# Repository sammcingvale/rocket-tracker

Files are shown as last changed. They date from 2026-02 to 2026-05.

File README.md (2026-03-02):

# 🚀 Rocket Tracker

A computer vision system that visually tracks model rockets in flight and points a laser at them. Built as a learning project covering OpenCV, Kalman filters, PID control, servo/brushless motor control, and real-time embedded systems.

## Project Phases

| Phase | Status | Description |
|---|---|---|
| 1. Software Tracking | ✅ Complete | Color detection + Kalman filter in OpenCV |
| 2. Pan/Tilt Gimbal | ✅ Complete | MG995 servos, Arduino UNO R4 WiFi, serial control |
| 3. Closed-Loop Control | ✅ Complete | Camera-on-gimbal PID tracking, person detection, live tuning |
| 4. Hardware Upgrade | 🔧 In Progress | Brushless gimbal motors (2804 + SimpleFOC), laser pointer |
| 5. Outdoor Rocket Tracking | 📋 Planned | Field testing with model rockets |

## System Architecture

```
Camera → OpenCV Detection → Kalman Filter → PID Controller → Serial → Arduino → Servos
  ↑                                                                              |
  └──────────────────── closed-loop feedback ──────────────────────────────────────┘
```

## Hardware Wiring

Hardware Wiring Diagram

### Current Hardware (Phase 2-3)
- Arduino UNO R4 WiFi
- 2x MG995 metal gear servos
- Bolsen aluminum pan/tilt bracket
- Logitech C920 webcam
- 6V 2A power supply

### Planned Hardware (Phase 4)
- MKS Dual FOC V3.2 + ESP32 controller
- 2x 2804 brushless gimbal motors with AS5600 encoders
- 5mW 650nm red laser module
- 12V 3A power supply

## Repository Structure

```
rocket-tracker/
├── vision/                     # Detection & tracking code
│   ├── track_color.py          # Phase 1a: HSV color detection with calibration
│   └── track_kalman.py         # Phase 1b: Kalman filter tracking
├── control/                    # Gimbal control code
│   ├── track_gimbal.py         # Phase 3: Closed-loop PID tracking (main script)
│   └── servo_serial.py         # Phase 2: Serial interface to Arduino
├── firmware/                   # Arduino code
│   └── servo_controller/
│       └── servo_controller.ino  # Servo control firmware (UNO R4 WiFi)
├── hardware/                   # Wiring diagrams, CAD files
│   └── wiring_diagram.svg
├── docs/                       # Documentation & learning resources
│   ├── notebook.md             # Engineering notebook / build log
│   ├── assembly_guide.md       # Step-by-step gimbal assembly instructions
│   ├── phase4_hardware.md      # Phase 4 shopping list & rationale
│   ├── camera_sensor_diagram.html  # Interactive: how camera sensors work
│   └── kalman_deep_dive.html   # Interactive: Kalman filter visualization
├── experiments/                # Test scripts
├── requirements.txt
└── README.md
```

## Quick Start

### Setup
```bash
git clone https://github.com/YOUR_USERNAME/rocket-tracker.git
cd rocket-tracker
python -m venv venv
source venv/bin/activate
pip install -r requirements.txt
```

### Phase 1: Software-Only Tracking (no hardware needed)
```bash
# Basic color detection — press 'c' to calibrate HSV
python vision/track_color.py

# With Kalman filter prediction
python vision/track_kalman.py
```

### Phase 2: Servo Testing
1. Upload `firmware/servo_controller/servo_controller.ino` via Arduino IDE
2. Board: Arduino UNO R4 WiFi, Baud: 115200
```bash
# Interactive servo commands
python control/servo_serial.py

# Automated demo sequence
python control/servo_serial.py --demo
```

### Phase 3: Closed-Loop Tracking
```bash
# Full tracking with gimbal (auto-detects Arduino)
python control/track_gimbal.py --camera 1

# Vision-only mode (no Arduino needed)
python control/track_gimbal.py --camera 0 --no-serial
```

#### Tracking Controls (press in camera window)
| Key | Action |
|-----|---|
| `q` | Quit |
| `h` | Home servos to center |
| `p` | Pause/resume tracking |
| `c` | Toggle HSV calibration |
| `s` | Print current HSV values |
| `1` / `2` / `3` | PID preset: conservative / balanced / aggressive |
| `+` / `-` | Fine-tune P gain |
| `x` / `y` | Flip pan / tilt direction |
| `m` | Toggle detection mode (color / person) |

#### HSV Calibration
Default values tuned for a red marker cap against mixed backgrounds:
- Lower: `[0, 180, 50]`
- Upper: `[10, 255, 255]`

Press `c` to open calibration sliders and adjust for your object/environment.

## Key Concepts Learned

### Computer Vision
- **HSV color space** — separating color (hue) from brightness for robust detection
- **Morphological operations** — erode/dilate to clean up binary masks
- **Contour detection** — finding object boundaries in filtered images

### State Estimation
- **Kalman filter** — predicting object position during detection dropouts using a constant-velocity model
- **Measurement vs. prediction** — using raw measurements for PID, Kalman only for coasting

### Control Theory
- **PID control** — proportional correction of pixel error to servo angle adjustment
- **Closed-loop feedback** — camera mounted on gimbal creates a true feedback loop
- **Tuning** — P-only control with dead zone works best for this system; I causes integral windup, D amplifies detection noise
- **Output clamping** — limiting max degrees/frame prevents saturation and oscillation

### Embedded Systems
- **Serial communication** — laptop ↔ Arduino over USB at 115200 baud
- **PWM servo control** — pulse width encoding for hobby servos
- **Common ground** — shared voltage reference between separate power supplies
- **Arduino UNO R4 WiFi** — USB CDC serial requires timeout on `while(!Serial)`

## Current PID Settings (Phase 3)

```
Conservative:  P=0.015  I=0  D=0  (output limit: 1.5°/frame)
Balanced:      P=0.03   I=0  D=0
Aggressive:    P=0.06   I=0  D=0
Dead zone:     ±15 pixels (ignores sub-pixel detection noise)
```

## License

This is a personal learning project. Feel free to use it for your own learning.

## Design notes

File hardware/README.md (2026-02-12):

# Hardware

CAD files, wiring diagrams, and BOM (bill of materials).

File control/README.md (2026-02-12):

# Control Module

PID loops, gimbal interface, and coordinate transforms.

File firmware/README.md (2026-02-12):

# Firmware

Arduino/embedded code for servo and motor control.

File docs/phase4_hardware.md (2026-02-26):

# Phase 4 Hardware Shopping List

## Why SimpleFOC Instead of BGC?

BGC (SimpleBGC/AlexMos) controllers are designed for camera *stabilization* — they use IMU data to keep a camera level despite external movement. That's the opposite of what we want. We need *active tracking*: "point at this angle, now this angle, now this angle" at high speed.

SimpleFOC is an open-source Arduino FOC (Field Oriented Control) library. It gives us direct position/velocity control of brushless motors using the same Arduino IDE workflow we already have. Same serial command interface, same development flow — just dramatically faster, smoother motors.

---

## The Shopping List

### 1. Motor Controller — MKS Dual FOC V3.2 + ESP32 (~$30-40)

**What:** A single board that drives TWO brushless motors, with an ESP32 microcontroller built in.

**Search:** "MKS Dual FOC V3.2 ESP32" on Amazon

**Why this one:**
- Drives both pan AND tilt motors from one board (no need for two drivers)
- ESP32 has WiFi + Bluetooth (wireless control later!)
- Built-in current sensors for FOC
- Directly compatible with the SimpleFOC Arduino library
- Programs through Arduino IDE just like your UNO R4
- 12V input, which matches the motors below

**Note:** Make sure you get the version WITH the ESP32 module (sometimes sold separately). The listing should say "Dual FOC Plus-ESP32" or similar.

---

### 2. Gimbal Motors (x2) — 2804 with AS5600 Encoder (~$15-20 each)

**What:** Brushless DC motors specifically designed for gimbals, with a magnetic position encoder built in.

**Search:** "2804 brushless gimbal motor AS5600 encoder" on Amazon
  - or "Makerbase gimbal motor 2804 AS5600"
  - DFRobot also sells a nice one (search "DFRobot 2804 BLDC")

**Why these:**
- The AS5600 encoder gives 12-bit resolution = 0.087° accuracy (vs ~1° with servos)
- SimpleFOC library has native AS5600 support over I2C
- Low KV rating = high torque at low speeds (perfect for gimbal, NOT for propellers)
- Compact: ~34mm diameter
- Hollow shaft design allows cable routing through the motor

**You need 2:** one for pan, one for tilt.

**Why brushless motors are faster than servos:**
Your MG995 servos have internal gears and top out at ~400°/sec with significant backlash. Brushless gimbal motors are direct-drive (no gears), so there's zero backlash and they can reposition in milliseconds. The motor *is* the joint.

---

### 3. Power Supply — 12V 3A DC Adapter (~$10-12)

**What:** Wall adapter to power the motors and controller.

**Search:** "12V 3A DC power supply barrel jack" on Amazon

**Why:** The 2804 motors are rated for 12V. Your existing 6V adapter won't work. 3A gives enough headroom for both motors under load.

**Alternative:** A 3S LiPo battery (11.1V) works too if you want it portable for outdoor testing later. But a wall adapter is simpler for now.

---

### 4. Laser Module — 5mW 650nm Red Dot (~$8-12)

**What:** A small focusable laser diode that mounts on the gimbal platform alongside the camera.

**Search:** "focusable 650nm 5mW red dot laser module 5V" on Amazon
  - The Adafruit one (product #1054) is reliable: "Adafruit laser diode 5mW 650nm"
  - Amazon generic: "adjustable focus 5mW 650nm laser diode module 3-5V"

**Specs to look for:**
- 650nm wavelength (red, highly visible)
- 5mW power (Class IIIa — visible but eye-safe at reasonable distances)
- 3-5V operating voltage (can be powered from the ESP32's 3.3V or 5V pin)
- Focusable lens (adjustable dot size for different distances)
- Wire leads (red +, black -)

**DO NOT buy anything over 5mW** — higher power lasers are dangerous and unnecessary. 5mW is bright enough to see the dot on a rocket at distance.

**Safety:** Never look directly into the beam or point it at people/aircraft. We'll add a software safety interlock (laser only activates when tracking is active).

---

### 5. Breadboard + Jumper Wires (~$8)

**What:** You still need a breadboard from Phase 2, and it'll be useful here too for prototyping connections.

**Search:** "mini breadboard jumper wire kit" on Amazon

---

### 6. Gimbal Frame — 3D Printed or Fabricated

**This is the one item you can't just buy off the shelf,** because the Bolsen bracket was designed for standard servos, not brushless motors.

**Options (pick one):**
- **3D print:** If you have access to a 3D printer (library, makerspace, friend), I can generate an STL file designed for the 2804 motors
- **Thingiverse:** Search "SimpleFOC 2804 pan tilt" — there are several community designs
- **Fabricate from aluminum L-brackets:** Buy some aluminum angle from a hardware store and drill mounting holes. Less pretty, but functional
- **Adapt the Bolsen bracket:** With creative mounting (epoxy, zip ties, 3D printed adapter plates), you might be able to attach 2804 motors to the existing bracket

We can figure this out once the electronic parts arrive. The software work can happen immediately.

---

## Summary

| Item | Est. Price | Notes |
|---|---|---|
| MKS Dual FOC V3.2 + ESP32 | ~$30-40 | One board drives both motors |
| 2804 Gimbal Motor + AS5600 (x2) | ~$30-40 | Position accuracy: 0.087° |
| 12V 3A Power Supply | ~$10-12 | Wall adapter for bench testing |
| 5mW 650nm Laser Module | ~$8-12 | Focusable, 3-5V, wire leads |
| Mini Breadboard + Wires | ~$8 | If you don't have one yet |
| Gimbal Frame | $0-30 | 3D print or fabricate |
| **TOTAL** | **~$86-140** | |

---

## What Changes in the Software

The great news: not much! The control flow stays the same:

```
Camera → OpenCV → Kalman → PID → Serial → Motor Controller → Motors
```

What changes:
- Arduino firmware switches from Servo library → SimpleFOC library
- Serial commands send precise float angles instead of integer degrees
- ESP32 replaces Arduino UNO R4 (but same Arduino IDE, same workflow)
- PID gains will need re-tuning (faster motors = less aggressive P needed)
- Add laser on/off control (digital pin HIGH/LOW)

Your UNO R4 + servos become your backup/test rig, which is handy.

---

## What To Do While Hardware Ships

1. **Mount the C920 on the current servo gimbal** and test closed-loop tracking
2. **Tune PID** on the servo system — this knowledge transfers directly
3. **I'll write the SimpleFOC firmware** so it's ready when parts arrive
4. **Build/find a gimbal frame design** for the 2804 motors

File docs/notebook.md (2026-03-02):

# Engineering Notebook

## Project: Rocket Tracker
**Goal:** Build a system that visually tracks model rockets in flight and points a laser at them.

---

## Phase 1: Software Tracking

### 1a: Color Detection (`vision/track_color.py`)
- HSV-based color detection for a red marker cap
- Gaussian blur → HSV conversion → binary mask → morphological ops → contour detection
- Interactive calibration mode with trackbars
- Key learning: HSV separates color from brightness, making detection robust to lighting changes
- Challenge: white backgrounds wash out saturation via auto-exposure; fast motion causes blur

### 1b: Kalman Filter (`vision/track_kalman.py`)
- Added constant-velocity Kalman filter (state: [x, y, vx, vy])
- Predict step extrapolates position using velocity model
- Update step blends prediction with measurement
- Coasts on velocity estimate when detection is lost
- Parameters: R=25 (measurement noise), Q_pos=4, Q_vel=16 (process noise)

### Interactive Learning Resources
- `docs/camera_sensor_diagram.html` — how camera sensors work (Bayer filter, demosaicing)
- `docs/kalman_deep_dive.html` — step-by-step Kalman filter visualization

---

## Phase 2: Pan/Tilt Gimbal

### Hardware
- Arduino UNO R4 WiFi
- 2x MG995 metal gear servos (pan on D9, tilt on D10)
- Bolsen aluminum 2-DOF pan/tilt bracket
- 6V 2A external power supply (servos powered separately from Arduino)
- Common ground between Arduino GND and servo power supply GND

### Firmware (`firmware/servo_controller/servo_controller.ino`)
- Serial command protocol: P<angle>, T<angle>, B<pan,tilt>, H (home), S (sweep), C (query)
- Smooth interpolation (STEP_SIZE=2, STEP_DELAY=5ms) to reduce jerk
- Baud rate: 115200
- Key fix: `while(!Serial)` must have a 3-second timeout on R4 WiFi, otherwise it blocks when connecting from pyserial (vs Arduino IDE Serial Monitor)

### Serial Interface (`control/servo_serial.py`)
- Auto-detects Arduino serial port across Mac/Linux/Windows
- Interactive mode + automated demo sequence
- 2-second delay after connection for Arduino bootloader reset

### Lessons Learned
- UNO R4 WiFi uses USB CDC (software serial), not hardware UART — `while(!Serial)` behaves differently than classic UNO
- Always power servos externally, never from Arduino 5V pin
- Common ground is mandatory for PWM signal integrity

---

## Phase 3: Closed-Loop Tracking

### System (`control/track_gimbal.py`)
- Camera mounted on gimbal creates true closed-loop feedback
- Detection → raw pixel error → PID → servo angle adjustment → serial → Arduino
- Kalman filter used only for coasting (when detection lost), NOT for PID input
- Key insight: Kalman velocity estimate is unreliable in closed-loop because apparent frame motion mixes object velocity with gimbal movement

### PID Tuning Journey
1. Started with P=0.06, I=0.002, D=0.02 — violent oscillation
2. Discovered output was saturating at ±5°/frame every frame (not proportional at all)
3. Reduced output limit to 1.5°/frame — proportional behavior restored
4. Zeroed I term — was causing integral windup and circling
5. Zeroed D term — was amplifying frame-to-frame detection noise (÷ by dt=0.033 → huge derivatives)
6. Added ±15px dead zone — stops chasing detection noise when nearly centered
7. Final: P-only control with output clamping and dead zone

### Final PID Settings
```
Conservative:  P=0.015  I=0  D=0  (best for stable tracking)
Balanced:      P=0.03   I=0  D=0  (slight circling on noisy backgrounds)
Aggressive:    P=0.06   I=0  D=0  (for fast targets)
Output limit:  1.5°/frame (45°/sec max at 30fps)
Dead zone:     ±15 pixels
```

### Direction Inversion
- Pan and tilt correction direction depends on physical servo mounting
- Runtime toggle: 'x' flips pan, 'y' flips tilt
- Current config: PAN_INVERT=1, TILT_INVERT=-1
- Also removed cv2.flip() mirror since camera is outward-facing on gimbal

### Serial Reliability
- Added write_timeout=0.1 to prevent blocking when Arduino buffer fills
- Added reset_input_buffer() before each write to drain responses
- Connection test: sends '?' and checks for response on startup

### HSV Calibration
- Original (Phase 1): lower=[160, 180, 0], upper=[179, 255, 255]
- Updated (Phase 3): lower=[0, 180, 50], upper=[10, 255, 255]
- Different shade of red (hue 0-10 vs 160-179), high saturation floor rejects white backgrounds

### Detection Smoothing
- Added rolling average of last N centroids (SMOOTH_WINDOW=3) between detection and PID
- Raw detection still feeds Kalman filter (it has its own smoothing)
- Smoothed detection feeds PID — reduces frame-to-frame jitter noticeably
- Buffer clears on detection loss to prevent stale data leaking in

### Home Position Calibration
- Python-side home() was sending firmware's hardcoded 'H' command (always 90/90)
- Fixed: home() now calls send_angles(SERVO_PAN_HOME, SERVO_TILT_HOME)
- Allows per-axis calibration in Python config (e.g., SERVO_TILT_HOME=80 to aim camera up)

### Person Tracking Mode
- Press 'm' to toggle between color detection and person detection
- Three cascading detectors in priority order:
  1. Upper body Haar cascade — works with torso + head visible (best for low camera)
  2. Face Haar cascade — works with head/shoulders only
  3. HOG full body — fallback when full body in frame
- Aiming point: center of detected region (chest for upper body, center for face)
- Lesson: HOG detector needs head-to-knees visible — useless from a low table
- Lesson: Haar cascades produce false positives on symmetric objects (grandfather clock, picture frames)

### Persistence Filter
- Problem: Haar cascades fire on furniture, clock pendulums, etc.
- Solution: new detections must appear within 80px of the same spot for 3 consecutive frames
- Once confirmed, single-frame detections accepted (no lag during active tracking)
- Resets after 10 frames without detection, requiring re-confirmation
- Tightened cascade thresholds: minNeighbors 3→5, larger minSize

### PID Tuning Dashboard
- Interactive React simulation of the gimbal system (`docs/pid_dashboard.jsx`)
- Same PID math, dead zone, output clamp, pixel-to-degree conversion as real system
- Drag target in camera view, adjust P/I/D sliders, watch real-time graphs
- Presets match real tracker (conservative, balanced, aggressive, try-I, try-D)
- Key experiments: I-term windup visible, saturation visible, dead zone behavior

### System Architecture Deep Dive
- Interactive 9-stage pipeline diagram (`docs/system_diagram.jsx`)
- Latency analysis: ~55ms total, servo response (20ms) is biggest bottleneck
- Two independent PID controllers (pan + tilt) with shared gains
- Three feedback loops identified: visual (intentional), mechanical coupling (parasitic), Kalman coasting (open-loop fallback)

### Current State
- Stable face tracking of walking person with conservative PID
- Detection is now the weakest link, not control — exactly where we want to be
- HSV color tracking hit its ceiling (lighting sensitivity, false matches)
- Haar cascades work but are brittle — neural detector (MobileNet SSD, MediaPipe) is the natural next step
- All PID/smoothing/persistence work carries forward regardless of detection method

---

## Phase 4: Brushless Motor Upgrade (hardware arrived!)

### Components
- MKS Dual FOC V3.2 + ESP32 (dual brushless motor driver)
- 2x 2804 brushless gimbal motor + AS5600 encoder
- 12V 3A power supply
- 5mW 650nm red laser module

### Why Brushless
- MG995 servos: ~400°/sec, ~1° accuracy, gear backlash, holding vibration
- 2804 brushless + AS5600: direct drive, 0.087° accuracy, no backlash, 1-3ms response
- Expected latency improvement: motor stage from ~20ms to ~2ms
- SimpleFOC library provides Arduino-compatible FOC control

### Key Challenge
- Two AS5600 encoders share same I2C address (0x36)
- Solution: one on I2C, one on analog/PWM output

### Frame
- Need custom 3D-printed frame for 2804 motors (Bolsen bracket is servo-specific)
- Access to makerspace for printing

---

## Phase 5: Outdoor Rocket Tracking (planned)

### Camera Considerations
- C920 may be sufficient at distance (rocket = few pixels, slow apparent motion)
- OV9281 global shutter module (720p@120fps) available as upgrade if needed (~$30-50)
- Decision: test with C920 first, upgrade based on real data

### Additional Challenges
- Sky backgrounds (blue/white) — will need different detection strategy
- Rocket is small at distance — few pixels to detect
- Motor burn exhaust — thermal signature as alternative detection
- Gravity — add gravity term to Kalman filter for ballistic prediction

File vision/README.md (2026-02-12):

# Vision Module

Detection and tracking code.

## Phase 1 Scripts
- `track_color.py` — basic color-based object tracking (first exercise)

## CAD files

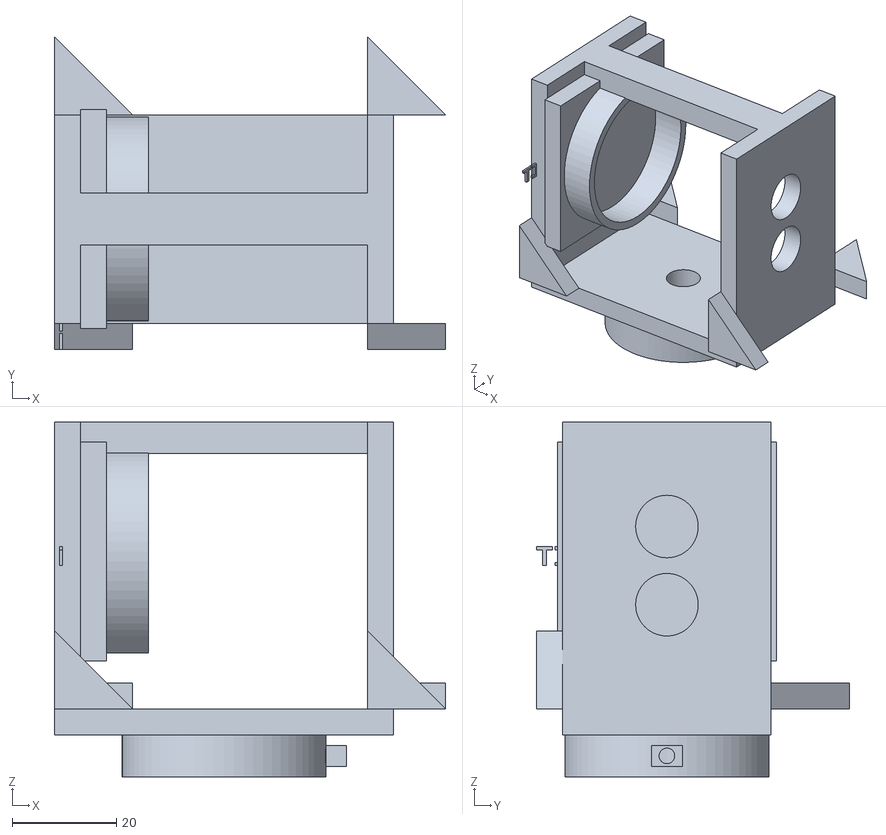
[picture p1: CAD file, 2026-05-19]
hardware/stl/gimbal_yoke.stl
75.0 x 60.0 x 68.0

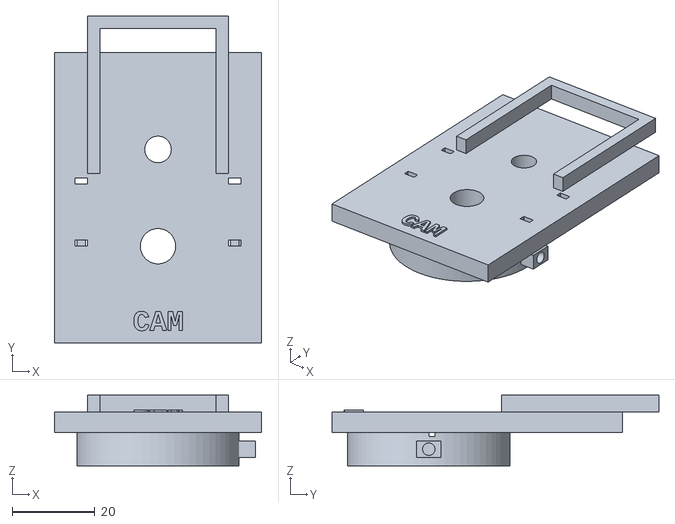
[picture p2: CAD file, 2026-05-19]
hardware/stl/gimbal_camera_mount.stl
50.0 x 78.8 x 17.0

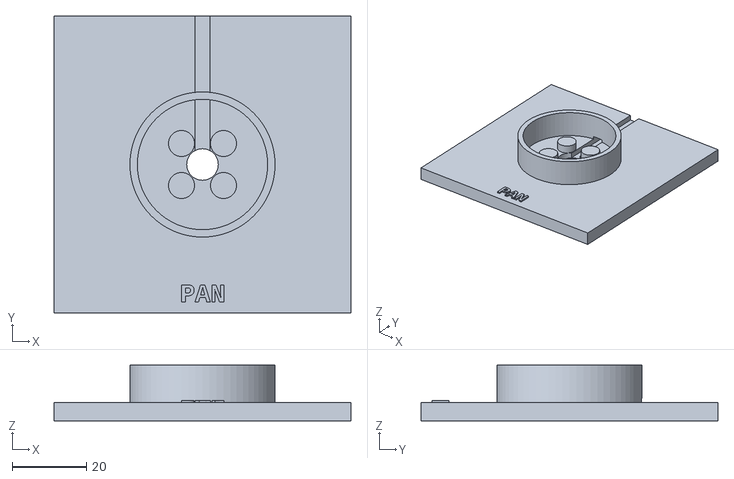
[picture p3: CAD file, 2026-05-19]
hardware/stl/gimbal_base.stl
80.0 x 80.0 x 15.0

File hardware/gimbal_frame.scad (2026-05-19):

/*
 * 2-Axis Pan/Tilt Gimbal Frame
 * For 2804 Hollow Shaft Outrunner Brushless Motors + AS5600 Encoders
 * 
 * HOW TO USE:
 *   1. Open this file in OpenSCAD (free: https://openscad.org/downloads)
 *   2. Uncomment ONE of the three lines at the bottom:
 *        base();
 *        yoke();
 *        camera_mount();
 *   3. Press F6 (Render)
 *   4. File → Export as STL
 *   5. Import STL into Bambu Studio
 *   6. Repeat for each part
 *
 * PRINT SETTINGS (Bambu P1S):
 *   Material: PLA or PETG
 *   Layer height: 0.2mm
 *   Infill: 30-40% (gyroid or grid)
 *   Walls: 3 perimeters
 *   Supports: YES for yoke (the arms overhang)
 *   Print yoke upright (arms pointing up)
 *   Print base flat (feet down)
 *   Print camera mount flat
 */

// ============================================================
// MOTOR DIMENSIONS — edit these if your measurements differ
// ============================================================
motor_dia       = 34.5;   // Motor body outer diameter
motor_height    = 15.0;   // Motor body height
bolt_circle     = 16.0;   // Mounting hole center-to-center (diagonal)
num_bolts       = 4;      // Number of mounting holes
screw_dia       = 2.2;    // M2 hole + clearance
screw_depth     = 3.0;    // Max screw depth into motor
hollow_shaft    = 6.5;    // Center hollow opening
magnet_dia      = 8.0;    // AS5600 magnet diameter (if applicable)

// ============================================================
// DESIGN PARAMETERS — tweak fit and strength
// ============================================================
tol             = 0.3;    // Print tolerance (increase if too tight)
wall            = 4.0;    // General wall thickness
$fn             = 64;     // Cylinder smoothness (increase for smoother)

// Derived
motor_r         = motor_dia / 2;
bolt_r          = bolt_circle / 2;
screw_r         = screw_dia / 2;

// ============================================================
// HELPER: Motor bolt hole pattern
// ============================================================
module bolt_holes(depth=10, extra_r=0) {
    for (i = [0:num_bolts-1]) {
        angle = 360 / num_bolts * i + 45; // 45° offset
        translate([bolt_r * cos(angle), bolt_r * sin(angle), 0])
            cylinder(h=depth, r=screw_r + extra_r, center=true);
    }
}

// ============================================================
// HELPER: Motor clamp ring
// ============================================================
module clamp_ring(height=10, inner_tol=0) {
    difference() {
        cylinder(h=height, r=motor_r + wall/2 + tol, center=false);
        translate([0, 0, -1])
            cylinder(h=height+2, r=motor_r + tol + inner_tol, center=false);
    }
}

// ============================================================
// PART 1: BASE
// ============================================================
module base() {
    base_w = 80;
    base_d = 80;
    base_h = 5;
    ring_h = 10;     // Motor retention ring height above base
    standoff_h = 3;  // Motor mount standoff height above base
    
    difference() {
        union() {
            // Main plate
            translate([-base_w/2, -base_d/2, 0])
                cube([base_w, base_d, base_h]);
            
            // Motor retention ring
            translate([0, 0, base_h])
                clamp_ring(height=ring_h);
            
            // Motor mounting standoffs
            for (i = [0:num_bolts-1]) {
                angle = 360 / num_bolts * i + 45;
                translate([bolt_r * cos(angle), bolt_r * sin(angle), base_h])
                    cylinder(h=standoff_h, r=3.5);
            }
        }
        
        // Subtract: motor mounting screw holes (through standoffs and base)
        translate([0, 0, -1])
            bolt_holes(depth=base_h + standoff_h + 4);
        
        // Subtract: center wiring hole
        translate([0, 0, -1])
            cylinder(h=base_h + ring_h + 4, r=hollow_shaft/2 + 1);
        
        // Subtract: cable channel to edge
        translate([-2, 0, base_h - 2])
            cube([4, base_d, 3]);
    }
    
    // Label
    translate([0, -base_d/2 + 3, base_h])
        linear_extrude(0.5)
            text("PAN", size=5, halign="center", font="Liberation Mono:style=Bold");
}

// ============================================================
// PART 2: YOKE (connects pan rotor → tilt motor)
// ============================================================
module yoke() {
    arm_h = 55;         // Arm height
    arm_t = wall + 1;   // Arm thickness (5mm)
    arm_d = 40;         // Arm depth (front-to-back)
    yoke_w = 65;        // Total width
    plate_h = 5;        // Bottom plate thickness
    clamp_depth = 8;    // Motor clamp ring depth (below plate)
    
    motor_z = plate_h + arm_h * 0.55;  // Tilt motor center height
    
    difference() {
        union() {
            // Bottom plate
            translate([-yoke_w/2, -arm_d/2, 0])
                cube([yoke_w, arm_d, plate_h]);
            
            // Motor clamp ring (goes below plate, fits over pan rotor)
            translate([0, 0, -clamp_depth])
                clamp_ring(height=clamp_depth + 1);
            
            // Left arm
            translate([-yoke_w/2, -arm_d/2, plate_h])
                cube([arm_t, arm_d, arm_h]);
            
            // Right arm
            translate([yoke_w/2 - arm_t, -arm_d/2, plate_h])
                cube([arm_t, arm_d, arm_h]);
            
            // Tilt motor mount plate (on inner face of left arm)
            mount_size = 42;
            mount_t = 5;
            translate([-yoke_w/2 + arm_t, -mount_size/2, motor_z - mount_size/2])
                cube([mount_t, mount_size, mount_size]);
            
            // Tilt motor retention ring (horizontal, on left mount plate)
            translate([-yoke_w/2 + arm_t + mount_t, 0, motor_z])
                rotate([0, 90, 0])
                    clamp_ring(height=8);
            
            // Top cross-brace
            brace_h = 6;
            brace_d = 10;
            translate([-yoke_w/2, -brace_d/2, plate_h + arm_h - brace_h])
                cube([yoke_w, brace_d, brace_h]);
            
            // Gussets (triangular reinforcement at arm bases)
            gusset_size = 15;
            // Left arm gussets
            for (sy = [-1, 1]) {
                translate([-yoke_w/2, sy * arm_d/2, plate_h])
                    rotate([90 * (sy > 0 ? 0 : 1), 0, 0])
                        linear_extrude(arm_t)
                            polygon([[0,0], [0, gusset_size], [gusset_size, 0]]);
            }
            // Right arm gussets  
            for (sy = [-1, 1]) {
                translate([yoke_w/2 - arm_t, sy * arm_d/2, plate_h])
                    rotate([90 * (sy > 0 ? 0 : 1), 0, 0])
                        linear_extrude(arm_t)
                            polygon([[0,0], [0, gusset_size], [gusset_size, 0]]);
            }
            
            // Set screw boss on motor clamp
            translate([motor_r + tol + wall/2, -3, -clamp_depth/2 - 2])
                cube([4, 6, 4]);
        }
        
        // Subtract: tilt motor mounting holes (through left mount plate)
        translate([-yoke_w/2 - 1, 0, motor_z])
            rotate([0, 90, 0])
                bolt_holes(depth=arm_t + 12);
        
        // Subtract: center hole in bottom plate for wiring
        translate([0, 0, -clamp_depth - 1])
            cylinder(h=plate_h + clamp_depth + 4, r=hollow_shaft/2 + 1);
        
        // Subtract: set screw hole
        translate([motor_r + tol - 1, 0, -clamp_depth/2])
            rotate([0, 90, 0])
                cylinder(h=wall + 6, r=1.5);  // M3 set screw
        
        // Subtract: weight reduction holes in arms (optional)
        for (zh = [plate_h + 20, plate_h + 35]) {
            translate([-yoke_w/2 - 1, 0, zh])
                rotate([0, 90, 0])
                    cylinder(h=arm_t + 2, r=6);
            translate([yoke_w/2 - arm_t - 1, 0, zh])
                rotate([0, 90, 0])
                    cylinder(h=arm_t + 2, r=6);
        }
    }
    
    // Labels
    translate([-yoke_w/2 + 1, -arm_d/2 + 3, plate_h + arm_h/2])
        rotate([90, 0, 90])
            linear_extrude(0.5)
                text("TILT→", size=4, halign="center", font="Liberation Mono:style=Bold");
}
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

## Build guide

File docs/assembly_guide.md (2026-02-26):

# Phase 2: Assembly & Wiring Guide

Step-by-step instructions for building the pan/tilt gimbal and wiring everything together.

**Time estimate:** 30–45 minutes

---

## What You Have

| Item | Quantity Needed |
|---|---|
| Bolsen aluminum pan/tilt bracket | 1 set (you have 2) |
| MG995 servos | 2 (you have 4) |
| Arduino UNO R4 WiFi | 1 |
| 6V 2A power adapter | 1 |
| Logitech C920 webcam | 1 |
| Dupont jumper wires | Several M-to-M and M-to-F |
| USB-C cable | 1 |
| Screws & servo horns (came with servos + bracket) | Various |

### What You Might Still Need

| Item | Why | Workaround |
|---|-----|---|
| Mini breadboard (~$5) | Easiest way to share power between 2 servos + ground | Can twist wires together instead (see Step 3 Option B) |
| Small Phillips screwdriver | For the bracket screws | — |

---

## STEP 1: Assemble the Pan/Tilt Bracket

The bracket kit has two main pieces of aluminum and a bag of screws/bearings. Here's how they go together.

### Understand the Parts

Open one set of the Bolsen bracket kit. You should find:

```
┌─────────────────────────────────┐
│  1x "L-shaped" or "U-shaped"   │   ← This is the TILT bracket
│     vertical bracket            │      (holds the camera platform)
│                                 │
│  1x Base plate / pan platform   │   ← This is the PAN bracket
│     (flat piece with holes)     │      (sits on the table)
│                                 │
│  1x Ball bearing                │   ← Goes between pan servo and base
│                                 │
│  1x Metal servo horn (round)    │   ← Attaches servo shaft to bracket
│                                 │
│  Bag of small screws            │   ← Various sizes for assembly
└─────────────────────────────────┘
```

### Assembly Order

**1a. Mount the PAN servo into the base plate.**

The base plate has a rectangular cutout that fits the MG995 servo body. The servo slides in from below so the output shaft (the nubby gear on top) pokes up through the hole. Use the screws that came with the bracket to secure the servo body to the base plate through the mounting tabs on either side of the servo.

```
        TOP VIEW (base plate)
    ┌──────────────────────────┐
    │                          │
    │    ┌──────────────┐      │
    │    │  servo body   │      │
    │    │   ┌──┐       │      │
    │    │   │⚙️│ shaft  │      │
    │    │   └──┘       │      │
    │    └──────────────┘      │
    │   screw↑          ↑screw │
    └──────────────────────────┘
```

**The servo wire should exit toward the back/bottom** — route it so it doesn't get pinched when the bracket rotates.

**1b. Attach the metal servo horn to the vertical bracket.**

Take the round metal servo horn disc. Screw it onto the bottom of the vertical/U-shaped bracket using the small screws. The horn has a splined center hole (star-shaped teeth) that will mate with the pan servo's output shaft.

**1c. Press the vertical bracket onto the pan servo shaft.**

Push the servo horn (now attached to the vertical bracket) down onto the pan servo's output shaft. The splines should mesh. You want this at approximately the center of the servo's range — so first power up and center the servo (we'll do this in Step 4), OR just eyeball it so the vertical bracket is roughly perpendicular to the base plate.

Secure with the small screw that goes into the top of the servo shaft (came with the servo).

**1d. Mount the TILT servo into the vertical bracket.**

The vertical U-shaped bracket has a rectangular cutout on one side. Mount the second MG995 servo into this cutout, with its output shaft pointing to the side. Screw it in using the bracket screws.

```
        SIDE VIEW (assembled)

          ┌───────────┐  ← camera/laser mount here
          │  TILT     │
          │  servo ⚙️──┤  ← tilt shaft points sideways
          │           │
          │  vertical │
          │  bracket  │
          │           │
          └─────┬─────┘
                │
           ┌────⚙️────┐   ← pan shaft points up
           │ PAN servo │
           └──────────┘
           ════════════   ← base plate (sits on table)
```

**1e. Attach a servo horn to the tilt output shaft.**

Use one of the servo horn "arms" (the cross-shaped or single-arm piece that came with the MG995 servos). Screw it onto the tilt servo's output shaft. This is where you'll eventually mount the camera. For now, just having the horn attached is fine.

**Don't mount the webcam yet** — let's verify the servos work first.

---

## STEP 2: Understand the Wiring

Before plugging anything in, let's understand what connects to what and why.

### The Three Circuits

Your system has three separate circuits that need to work together:

```
CIRCUIT 1: SERVO POWER                    CIRCUIT 2: ARDUINO
(6V adapter → servos)                     (USB → Arduino)

  ┌──────────┐    ┌─────────┐             ┌──────┐    ┌─────────┐
  │ 6V Power │───→│ Servo 1 │             │Laptop│───→│ Arduino │
  │ Adapter  │───→│ Servo 2 │             │ USB  │    │ UNO R4  │
  └──────────┘    └─────────┘             └──────┘    └─────────┘
       Has its own GND ←──────────────────────→ Has its own GND

                        ↑
                        │
              These two GNDs MUST be
              connected together!
              (That's the "common ground")

CIRCUIT 3: SIGNAL (connects 1 and 2)

  Arduino Pin 9  ──── orange wire ────→ Pan servo signal
  Arduino Pin 10 ──── orange wire ────→ Tilt servo signal
  Arduino GND    ──── purple wire ────→ Power supply GND
                                        (common ground)
```

### Why Common Ground Matters

The Arduino sends a PWM signal (a pulse of voltage) on pins 9 and 10. The servo reads this pulse to know what angle to move to. But voltage is *relative* — it's the difference between two wires. The servo measures the signal voltage relative to its own ground. If the servo's ground and the Arduino's ground aren't connected, they could be at completely different voltage levels, and the servo would misread the signal.

Think of it like this: if I say "the shelf is 3 feet up," you need to know *from what*. From the floor? From the table? The common ground is the "floor" that both devices agree on.

### The Servo Wire Colors (MG995)

Each MG995 servo has a 3-pin connector with three wires:

```
┌────────────────────────────────────┐
│  Brown wire  = GND  (ground)       │
│  Red wire    = +V   (power, 5-6V)  │
│  Orange wire = SIG  (PWM signal)   │
└────────────────────────────────────┘
```

---

## STEP 3: Wire It Up

### Option A: With a Breadboard (recommended)

A breadboard makes this clean and easy. The two long rails on the sides are the power bus.

```
BREADBOARD LAYOUT
═══════════════════════════════════════════════

  (+) ●───●───●───●───●───●───●───●  ← Red rail (+6V)
  (-) ●───●───●───●───●───●───●───●  ← Blue rail (GND)

  Row connections in the middle:
  a  ●   ●   ●   ●   ●   ●   ●   ●
  b  ●   ●   ●   ●   ●   ●   ●   ●
  c  ●   ●   ●   ●   ●   ●   ●   ●
  d  ●   ●   ●   ●   ●   ●   ●   ●
  e  ●   ●   ●   ●   ●   ●   ●   ●

═══════════════════════════════════════════════
```

**Step 3A-1: Connect the power adapter to the breadboard power rails.**

Your 6V adapter has a barrel jack. You need to get the +6V and GND wires onto the breadboard. Options:
- **Barrel jack breakout board** (if you bought one) — plug adapter in, screw terminals give you +/- wires
- **Cut the barrel jack off** — strip the wires (center wire = +6V, outer braid = GND). Use a multimeter to verify polarity if you're unsure!
- **If your adapter came with screw terminal tips** (check the interchangeable tips in your kit) — one of those tips might have bare wire leads

Connect:
- **+6V** (red wire from adapter) → breadboard **red (+) rail**
- **GND** (black wire from adapter) → breadboard **blue (-) rail**

⚠️ **Don't plug the adapter into the wall yet!** Wire everything first, double-check, then apply power last.

**Step 3A-2: Connect both servos to the breadboard.**

For EACH servo (pan and tilt):

| Servo Wire | Connects To |
|---|---|
| Red (+V) | Breadboard red (+) rail |
| Brown (GND) | Breadboard blue (-) rail |
| Orange (SIG) | Leave free for now (goes to Arduino) |

You'll need to use dupont jumper wires to bridge from the servo's 3-pin connector to the breadboard. **Male-to-male** wires work for this: push one end into the servo connector pin, the other into the breadboard.

**Step 3A-3: Connect the common ground.**

Use a dupont jumper wire to connect:
- Breadboard **blue (-) rail** → Arduino **GND pin**

This is the common ground! It connects the servo power supply's ground to the Arduino's ground.

```
BREADBOARD WIRING DIAGRAM

         (+) rail ←── 6V adapter (+)
         (─) rail ←── 6V adapter (-)
              │
              ├── Pan servo RED wire
              ├── Tilt servo RED wire    (both to + rail)
              │
         (─) rail
              ├── Pan servo BROWN wire
              ├── Tilt servo BROWN wire  (both to - rail)
              │
              └── jumper wire ──→ Arduino GND pin
                  (COMMON GROUND)
```

**Step 3A-4: Connect signal wires to Arduino.**

Use dupont jumper wires:

| From | To | Wire Color (suggestion) |
|---|----|---|
| Pan servo ORANGE wire | Arduino pin **D9** | Use a yellow/orange dupont wire |
| Tilt servo ORANGE wire | Arduino pin **D10** | Use a different color so you can tell them apart |

### Option B: Without a Breadboard (twisted wires)

If you want to start right now and don't have a breadboard:

1. Take 3 male-to-male dupont wires
2. Twist/connect the **red** wires from both servos together, plus the +6V from your power adapter → all three reds joined
3. Twist/connect the **brown** wires from both servos together, plus the GND from your power adapter, plus a wire going to Arduino GND → all four browns/blacks joined
4. You can use electrical tape to insulate the twisted connections

This works but is fragile. Get a breadboard when you can.

---

## STEP 4: Connect the Arduino

**4-1.** Plug the USB-C cable into the Arduino and into your laptop. The Arduino should power on (you'll see an LED light up).

**4-2.** Double-check signal wire connections:
- Pin D9 → Pan servo signal (orange)
- Pin D10 → Tilt servo signal (orange)
- GND pin → Common ground (to breadboard - rail or servo ground junction)

**4-3.** Do NOT connect anything to the Arduino's 5V pin. The servos get their power from the external 6V supply, not from the Arduino.

---

## STEP 5: Flash and Test

**5-1. Install Arduino IDE** if you haven't already:
- Download from https://www.arduino.cc/en/software
- Install the **Arduino UNO R4 Boards** package: Tools → Board → Boards Manager → search "UNO R4" → Install

**5-2. Open the firmware:**
- Open `firmware/servo_controller/servo_controller.ino` in Arduino IDE

**5-3. Select your board and port:**
- Tools → Board → Arduino UNO R4 Boards → **Arduino UNO R4 WiFi**
- Tools → Port → select the one that says "Arduino UNO R4 WiFi" (on Mac it'll be something like `/dev/cu.usbmodemXXXX`)

**5-4. Upload:**
- Click the Upload button (→ arrow)
- Wait for "Done uploading"

**5-5. Open Serial Monitor:**
- Tools → Serial Monitor
- Set baud rate to **115200** (bottom-right dropdown)
- Set line ending to **Newline** (dropdown next to baud rate)

**5-6. NOW plug in the 6V power adapter.**

You should see the startup message in the serial monitor:
```
=== Rocket Tracker Servo Controller ===
Type '?' for help
Ready at 90,90
```

The servos should twitch slightly as they move to the 90° home position.

**5-7. Test commands:**

Type each of these in the Serial Monitor input box and press Enter:

```
H          → Both servos center to 90° (you should see/hear them move)
P30        → Pan servo rotates to 30°
P150       → Pan servo rotates to 150°
T30        → Tilt servo moves to 30°
T150       → Tilt servo moves to 150°
B90,90     → Both return to center
S          → Start sweep test (both slowly sweep back and forth)
S          → Stop sweep test
```

---

## STEP 6: Test from Python

Close the Arduino IDE Serial Monitor first (only one program can use the serial port at a time).

```bash
cd rocket-tracker
source venv/bin/activate
pip install pyserial
python control/servo_serial.py --demo
```

You should see the gimbal cycle through a sequence: center, look left, look right, look up, look down, and back to center.

---

## Troubleshooting

| Symptom | Likely Cause | Fix |
|---|---|-----|
| Servos don't move at all | No power to servos | Check 6V adapter is plugged in, check red/brown wires on breadboard |
| Servos jitter/twitch randomly | Missing common ground | Add jumper wire from breadboard GND rail to Arduino GND |
| Arduino resets when servos move | Servos drawing power from Arduino | Make sure servo red wires go to 6V adapter, NOT to Arduino 5V pin |
| Only one servo works | Signal wire on wrong pin | Check that pan=D9, tilt=D10 |
| Serial monitor shows garbage | Wrong baud rate | Set to 115200 |
| Python can't find serial port | Wrong port or Serial Monitor still open | Close Serial Monitor, try `ls /dev/tty.usb*` to find the port |
| Servo moves to wrong angle | Servo horn mounted at wrong starting position | Remove horn, center servo with `H` command, reattach horn at 90° |

---

## What's Next

Once you've verified both servos respond correctly to commands:
1. Mount the webcam on the tilt platform (zip ties, velcro, or 3D printed bracket)
2. We'll write the Phase 3 code that connects the tracking script to the gimbal — the camera detects the object, Kalman filter predicts its position, and the servo controller points the gimbal to follow it

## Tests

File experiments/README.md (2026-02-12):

# Experiments

Quick test scripts, benchmarks, and one-off explorations.

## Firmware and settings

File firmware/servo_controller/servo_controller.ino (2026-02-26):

/*
 * ROCKET TRACKER — Phase 2: Pan/Tilt Servo Controller
 * =====================================================
 *
 * This firmware runs on the Arduino UNO R4 WiFi and controls two MG995
 * servos (pan + tilt) based on commands received over USB serial.
 *
 * WIRING:
 *   Pan servo  signal → Pin 9
 *   Tilt servo signal → Pin 10
 *   Servo power       → External 6V supply (NOT from Arduino!)
 *   Common ground     → Arduino GND ↔ Servo power supply GND
 *
 * SERIAL PROTOCOL:
 *   Commands are simple text lines ending with newline (\n):
 *
 *   "P<angle>"       — Set pan angle  (e.g., "P90" → pan to 90°)
 *   "T<angle>"       — Set tilt angle (e.g., "T45" → tilt to 45°)
 *   "B<pan>,<tilt>"  — Set both at once (e.g., "B90,45")
 *   "C"              — Report current angles (response: "C<pan>,<tilt>")
 *   "H"              — Home position (center both servos to 90°)
 *   "S"              — Sweep test (pan and tilt cycle through range)
 *   "?"              — Print help
 *
 *   Angles are clamped to [MIN_ANGLE, MAX_ANGLE] for safety.
 *
 * TESTING WITHOUT PYTHON:
 *   1. Upload this sketch to your Arduino
 *   2. Open Serial Monitor (Tools → Serial Monitor)
 *   3. Set baud rate to 115200, line ending to "Newline"
 *   4. Type "H" to center servos
 *   5. Type "S" to run sweep test
 *   6. Type "P45" or "T120" to move individual servos
 *
 * LEARNING NOTES:
 *   Servos are controlled via PWM (Pulse Width Modulation). The Arduino
 *   Servo library handles the details, but under the hood:
 *     - A pulse is sent every 20ms (50 Hz)
 *     - Pulse width of ~1000μs = 0°
 *     - Pulse width of ~1500μs = 90° (center)
 *     - Pulse width of ~2000μs = 180°
 *   The servo's internal circuitry reads this pulse width and drives the
 *   motor to the corresponding angle. This is why we need hardware PWM
 *   pins (9 and 10 on the UNO) — they can generate precise pulse timing.
 */

#include <Servo.h>

// ─── PIN CONFIGURATION ──────────────────────────────────────────
#define PAN_PIN   9
#define TILT_PIN  10

// ─── ANGLE LIMITS ───────────────────────────────────────────────
// Safety clamps — adjust these based on your physical setup to
// prevent the gimbal from hitting its own frame or wires.
#define PAN_MIN   10
#define PAN_MAX   170
#define TILT_MIN  10
#define TILT_MAX  170

// Default (home) position — center of range
#define PAN_HOME  90
#define TILT_HOME 90

// ─── SMOOTHING ──────────────────────────────────────────────────
// Instead of jumping instantly to a target angle (which causes
// jerky motion and high current spikes), we interpolate smoothly.
// STEP_DELAY_MS controls how fast the servo moves (smaller = faster).
// STEP_SIZE controls how far it moves per step (larger = faster but jerkier).
#define STEP_DELAY_MS  5
#define STEP_SIZE      2

// ─── SERIAL ─────────────────────────────────────────────────────
#define BAUD_RATE  115200
#define BUF_SIZE   32

// ─── GLOBALS ────────────────────────────────────────────────────
Servo panServo;
Servo tiltServo;

int panAngle  = PAN_HOME;
int tiltAngle = TILT_HOME;

int panTarget  = PAN_HOME;
int tiltTarget = TILT_HOME;

char inputBuffer[BUF_SIZE];
int bufferIndex = 0;

bool sweepMode = false;
int sweepPanDir = 1;
int sweepTiltDir = 1;

// ─── SETUP ──────────────────────────────────────────────────────
void setup() {
  Serial.begin(BAUD_RATE);
  // Wait up to 3 seconds for USB serial to connect.
  // Arduino IDE Serial Monitor triggers this quickly;
  // pyserial may not, so we use a timeout to avoid hanging.
  unsigned long serialWaitStart = millis();
  while (!Serial && (millis() - serialWaitStart < 3000)) {
    ; // wait
  }
  delay(200); // Extra settle time

  panServo.attach(PAN_PIN);
  tiltServo.attach(TILT_PIN);

  // Start at home position
  panServo.write(PAN_HOME);
  tiltServo.write(TILT_HOME);
  panAngle = PAN_HOME;
  tiltAngle = TILT_HOME;
  panTarget = PAN_HOME;
  tiltTarget = TILT_HOME;

  delay(500); // Let servos reach home position

  Serial.println("=== Rocket Tracker Servo Controller ===");
  Serial.println("Type '?' for help");
  Serial.print("Ready at ");
  Serial.print(PAN_HOME);
  Serial.print(",");
  Serial.println(TILT_HOME);
}

// ─── MAIN LOOP ──────────────────────────────────────────────────
void loop() {
  // Check for serial commands
  readSerial();

  // If sweep test is active, run it
  if (sweepMode) {
    runSweep();
  }

  // Smoothly move servos toward their targets
  updateServos();
}

// ─── SERIAL READING ─────────────────────────────────────────────
void readSerial() {
  while (Serial.available() > 0) {
    char c = Serial.read();

    if (c == '\n' || c == '\r') {
      if (bufferIndex > 0) {
        inputBuffer[bufferIndex] = '\0'; // Null-terminate
        processCommand(inputBuffer);
        bufferIndex = 0;
      }
    } else if (bufferIndex < BUF_SIZE - 1) {
      inputBuffer[bufferIndex++] = c;
    }
  }
}

// ─── COMMAND PROCESSING ─────────────────────────────────────────
void processCommand(char* cmd) {
  switch (cmd[0]) {

    case 'P': case 'p': {
      // Pan to angle: "P90"
      int angle = atoi(&cmd[1]);
      panTarget = constrain(angle, PAN_MIN, PAN_MAX);
      sweepMode = false;
      Serial.print("PAN → ");
      Serial.println(panTarget);
      break;
    }

    case 'T': case 't': {
      // Tilt to angle: "T45"
      int angle = atoi(&cmd[1]);
      tiltTarget = constrain(angle, TILT_MIN, TILT_MAX);
      sweepMode = false;
      Serial.print("TILT → ");
      Serial.println(tiltTarget);
      break;
    }

    case 'B': case 'b': {
      // Both: "B90,45"
      int pan, tilt;
      if (sscanf(&cmd[1], "%d,%d", &pan, &tilt) == 2) {
        panTarget  = constrain(pan, PAN_MIN, PAN_MAX);
        tiltTarget = constrain(tilt, TILT_MIN, TILT_MAX);
        sweepMode = false;
        Serial.print("BOTH → ");
        Serial.print(panTarget);
        Serial.print(",");
        Serial.println(tiltTarget);
      } else {
        Serial.println("ERR: use B<pan>,<tilt>");
      }
      break;
    }

    case 'C': case 'c': {
      // Report current position
      Serial.print("C");
      Serial.print(panAngle);
      Serial.print(",");
      Serial.println(tiltAngle);
      break;
    }

    case 'H': case 'h': {
      // Home
      panTarget  = PAN_HOME;
      tiltTarget = TILT_HOME;
      sweepMode = false;
      Serial.println("HOME → 90,90");
      break;
    }

    case 'S': case 's': {
      // Toggle sweep test
      sweepMode = !sweepMode;
      if (sweepMode) {
        Serial.println("SWEEP ON");
      } else {
        Serial.println("SWEEP OFF");
      }
      break;
    }

    case '?': {
      printHelp();
      break;
    }

    default:
      Serial.print("ERR: unknown command '");
      Serial.print(cmd[0]);
      Serial.println("' — type '?' for help");
      break;
  }
}

// ─── SMOOTH SERVO UPDATE ────────────────────────────────────────
/*
 * Instead of jumping to the target angle instantly, we step toward
 * it gradually. This:
 *   1. Reduces mechanical stress on the gears
 *   2. Lowers current spikes (less brownout risk)
 *   3. Looks smoother
 *
 * In Phase 3, we'll replace this with a proper PID controller that
 * receives continuous position updates from the tracking loop.
 * For now, simple interpolation is fine for testing.
 */
void updateServos() {
  static unsigned long lastStep = 0;
  unsigned long now = millis();

  if (now - lastStep < STEP_DELAY_MS) return;
  lastStep = now;

  // Step pan toward target
  if (panAngle < panTarget) {
    panAngle = min(panAngle + STEP_SIZE, panTarget);
  } else if (panAngle > panTarget) {
    panAngle = max(panAngle - STEP_SIZE, panTarget);
  }

  // Step tilt toward target
  if (tiltAngle < tiltTarget) {
    tiltAngle = min(tiltAngle + STEP_SIZE, tiltTarget);
  } else if (tiltAngle > tiltTarget) {
    tiltAngle = max(tiltAngle - STEP_SIZE, tiltTarget);
  }

  panServo.write(panAngle);
  tiltServo.write(tiltAngle);
}

// ─── SWEEP TEST ─────────────────────────────────────────────────
/*
 * Slowly sweeps both servos back and forth across their full range.
 * Useful for:
 *   - Verifying both servos work and move freely
 *   - Checking that the bracket doesn't bind or hit anything
 *   - Making sure the power supply can handle both moving at once
 */
void runSweep() {
  static unsigned long lastSweep = 0;
  unsigned long now = millis();

  if (now - lastSweep < 30) return;
  lastSweep = now;

  panTarget += sweepPanDir;
  if (panTarget >= PAN_MAX) { panTarget = PAN_MAX; sweepPanDir = -1; }
  if (panTarget <= PAN_MIN) { panTarget = PAN_MIN; sweepPanDir = 1; }

  tiltTarget += sweepTiltDir;
  if (tiltTarget >= TILT_MAX) { tiltTarget = TILT_MAX; sweepTiltDir = -1; }
  if (tiltTarget <= TILT_MIN) { tiltTarget = TILT_MIN; sweepTiltDir = 1; }
}

// ─── HELP TEXT ──────────────────────────────────────────────────
void printHelp() {
  Serial.println("=== Servo Controller Commands ===");
  Serial.println("  P<angle>       Pan to angle (10-170)");
  Serial.println("  T<angle>       Tilt to angle (10-170)");
  Serial.println("  B<pan>,<tilt>  Set both angles");
  Serial.println("  C              Report current angles");
  Serial.println("  H              Home (center to 90,90)");
  Serial.println("  S              Toggle sweep test");
  Serial.println("  ?              Show this help");
  Serial.println("================================");
}

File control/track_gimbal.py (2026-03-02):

"""
Phase 3: Closed-Loop Object Tracking with Pan/Tilt Gimbal

THIS IS WHERE IT ALL COMES TOGETHER:
  Camera → Detection → Kalman Filter → PID Controller → Serial → Arduino → Servos
  
  The camera sees an object. OpenCV detects it. The Kalman filter predicts
  its position. The PID controller calculates how much to adjust the servo
  angles to center the object in the frame. The Arduino moves the servos.
  Next frame, repeat.

HOW THE PID CONTROLLER WORKS:
  The "error" is how far the object is from the center of the frame, in pixels.
  The PID controller converts this pixel error into a servo angle adjustment:

    P (Proportional): Correction proportional to the error RIGHT NOW.
        Object is 100px left of center → turn left proportionally.
        Larger P = more aggressive response, but can overshoot.

    I (Integral): Correction based on ACCUMULATED past error.
        If the object has been slightly left for many frames, I builds up
        and pushes harder. Fixes steady-state offset.
        Larger I = eliminates persistent error, but can cause oscillation.

    D (Derivative): Correction based on how fast the error is CHANGING.
        If the object is moving left quickly, D applies extra correction.
        Acts as a damper — reduces overshoot and jitter.
        Larger D = smoother, but can slow response.

  output = P * error + I * sum(past_errors) + D * (error - prev_error)

USAGE:
    python track_gimbal.py --camera 1
    python track_gimbal.py --camera 1 --port /dev/tty.usbmodem1101
    python track_gimbal.py --camera 1 --calibrate

CONTROLS:
    q       — quit
    c       — toggle HSV calibration
    s       — save HSV values
    k       — toggle Kalman visualization
    p       — pause/resume tracking (servos hold position)
    h       — home servos to center
    1/2/3   — PID presets (conservative / balanced / aggressive)
    +/-     — fine-tune P gain up/down

TIP: Start with the object close to center, then slowly move it around.
     If the gimbal oscillates (shakes back and forth), reduce P gain with '-'.
"""

import argparse
import time
import sys
import glob
import cv2
import numpy as np
from filterpy.kalman import KalmanFilter
import serial


# ---------------------------------------------------------------------------
# HSV RANGE — paste your calibrated values from Phase 1
# ---------------------------------------------------------------------------
DEFAULT_LOWER = np.array([0, 180, 50])
DEFAULT_UPPER = np.array([10, 255, 255])

MIN_CONTOUR_AREA = 500

# ---------------------------------------------------------------------------
# SERVO CONFIGURATION
# ---------------------------------------------------------------------------
# Adjust HOME values so the gimbal points straight ahead at startup.
# If your gimbal is slightly right/up at home, tweak these:
SERVO_PAN_HOME  = 90    # Decrease to point more left, increase for right
SERVO_TILT_HOME = 90    # Decrease to tilt down, increase to tilt up
SERVO_MIN       = 10
SERVO_MAX       = 170

# ---------------------------------------------------------------------------
# DETECTION SMOOTHING
# ---------------------------------------------------------------------------
# Rolling average of the last N centroids to reduce jitter.
# Higher = smoother but adds latency. 3-5 is a good range.
SMOOTH_WINDOW = 3

# ---------------------------------------------------------------------------
# DIRECTION INVERSION
# ---------------------------------------------------------------------------
# These flip the correction direction for each axis.
# If the gimbal runs away when it sees the object, flip the relevant axis.
# Press 'x' to flip pan direction, 'y' to flip tilt direction.
PAN_INVERT  = 1     # 1 or -1
TILT_INVERT = -1    # 1 or -1

# ---------------------------------------------------------------------------
# PID PRESETS
# ---------------------------------------------------------------------------
# These map pixel error → servo angle adjustment per frame.
# Start conservative and increase if tracking is too sluggish.
#
# The values are tuned for 640x480 resolution where the max error
# from center is ~320px horizontally, ~240px vertically.

PID_PRESETS = {
    "conservative": {"P": 0.015, "I": 0.0, "D": 0.0},
    "balanced":     {"P": 0.03,  "I": 0.0, "D": 0.0},
    "aggressive":   {"P": 0.06,  "I": 0.0, "D": 0.0},
}

DEFAULT_PID = "balanced"


# ---------------------------------------------------------------------------
# PID CONTROLLER
# ---------------------------------------------------------------------------
class PIDController:
    """
    Simple PID controller for one axis (pan or tilt).

    Input:  pixel error (object position - frame center)
    Output: servo angle adjustment (degrees per frame)

    LEARNING NOTES:
    ───────────────
    A PID controller is a feedback loop. It measures the error between
    where we ARE and where we WANT TO BE, then outputs a correction.

    The three terms work together:
    - P gets you close quickly (but overshoots)
    - D slows you down as you approach (reduces overshoot)
    - I cleans up any remaining offset over time

    Without D, the gimbal will oscillate around the target.
    Without I, it might settle with a small persistent offset.
    Without P, it barely moves at all.

    The trick is tuning: too much P = oscillation, too much I = slow
    oscillation that builds up, too much D = sluggish and jittery.
    """

    def __init__(self, kp, ki, kd, output_limit=1.5):
        self.kp = kp
        self.ki = ki
        self.kd = kd
        self.output_limit = output_limit  # Max degrees per frame

        self.prev_error = 0.0
        self.integral = 0.0
        self.integral_limit = 100.0  # Anti-windup clamp

    def update(self, error, dt):
        """
        Compute PID output given current error and time step.

        Returns a servo angle adjustment in degrees.
        """
        # Proportional: react to current error
        p_term = self.kp * error

        # Integral: accumulate past error (with anti-windup)
        self.integral += error * dt
        self.integral = max(-self.integral_limit,
                           min(self.integral_limit, self.integral))
        i_term = self.ki * self.integral

        # Derivative: react to rate of change
        if dt > 0:
            derivative = (error - self.prev_error) / dt
        else:
            derivative = 0.0
        d_term = self.kd * derivative

        self.prev_error = error

        # Sum and clamp
        output = p_term + i_term + d_term
        output = max(-self.output_limit, min(self.output_limit, output))

        return output

    def reset(self):
        """Reset accumulated state."""
        self.prev_error = 0.0
        self.integral = 0.0
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

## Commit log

2026-02-18 phase 2 wiring diagram
2026-02-18 wiring diagram readme updates
2026-02-18 Arduino firmware for basic pan/ tilt servo control
2026-02-23 we movin servos
2026-02-26 Phase 3 complete: closed-loop PID tracking with pan/tilt gimbal
    - vision/: color detection + Kalman filter tracking
    - control/: closed-loop gimbal tracker with PID tuning
    - firmware/: Arduino servo controller (UNO R4 WiFi)
    - hardware/: wiring diagram (SVG, renders in README)
    - docs/: assembly guide, engineering notebook, interactive tutorials
    - Tuned PID: P-only control, 1.5°/frame limit, 15px dead zone
2026-03-02 i can track humans
2026-05-19 phase 4 gimbal frame
    [gimbal_base.stl, gimbal_camera_mount.stl, gimbal_frame.scad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]
